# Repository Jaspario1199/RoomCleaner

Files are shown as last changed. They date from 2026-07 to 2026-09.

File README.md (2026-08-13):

# RoomCleaner 🧺🤖

An autonomous robot that scans your room, spots dirty laundry on the floor,
picks it up, and drops it in the hamper — using four winch motors in the
ceiling corners and a downward-facing gripper on cables.

> **▶ Interactive showcase:** [`showcase/index.html`](showcase/) — a live,
> self-contained portfolio page (browser simulation + engineering analysis +
> CAD). Open it in a browser or host it free on GitHub Pages.

> **Status:** Phase 0 complete + Phase 1 scaffolded. The kinematics, fan-aware
> motion planning, auto rest-pose, and the full scan→grab→deliver loop run today
> with **zero hardware**; a real open-vocabulary laundry detector runs on a
> webcam. You only need to fill in your room dimensions and ceiling-fan location.

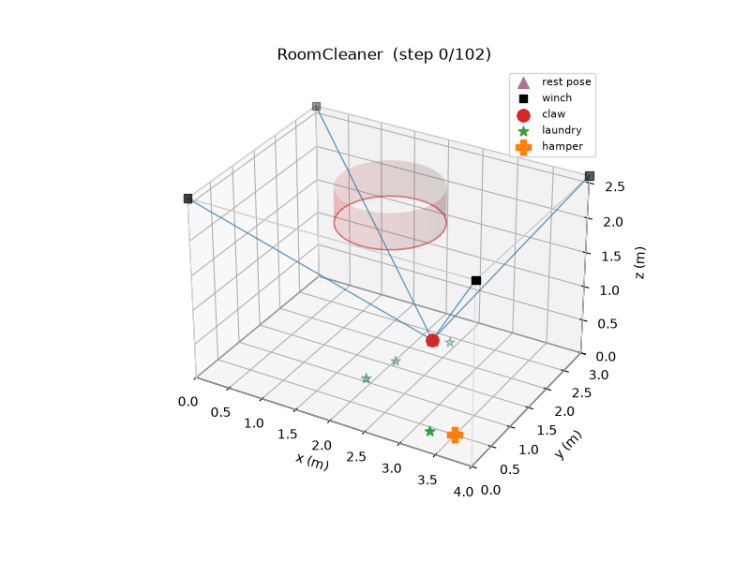
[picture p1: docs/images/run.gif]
A cleaning run in simulation


---

## The idea in one picture

The machine is a **Cable-Driven Parallel Robot (CDPR)** — the same mechanism
that flies the "SkyCam" over a football stadium. Four motorized winches sit in
the ceiling corners; each pays out or reels in a cable. Where the cables meet is
the end-effector (the "claw"). Control the four cable lengths and you control the
claw's position anywhere in the room.

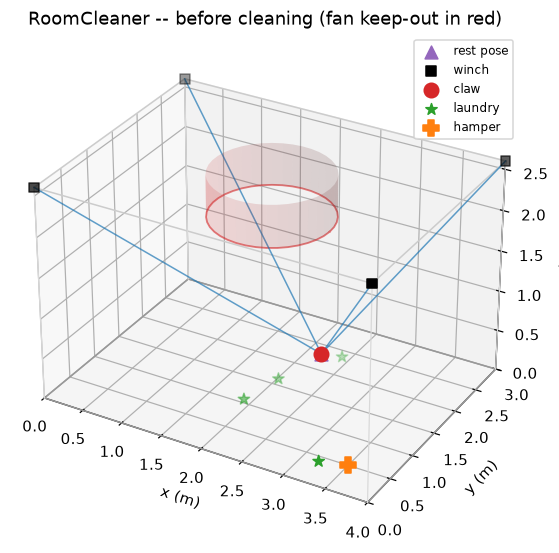
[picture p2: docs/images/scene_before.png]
The robot in its room


**Why a cable robot instead of arms or a rolling vacuum?**
- It reaches the *whole floor* from above — no bumping into furniture.
- The heavy motors stay bolted to the ceiling; only a light claw moves.
- The math (below) is clean and the parts are cheap.

The trade-off is the reachable area shrinks near the walls (cables can't pull the
claw sideways into a corner). Here's the safe workspace at a low height — green is
reachable, pink is not:

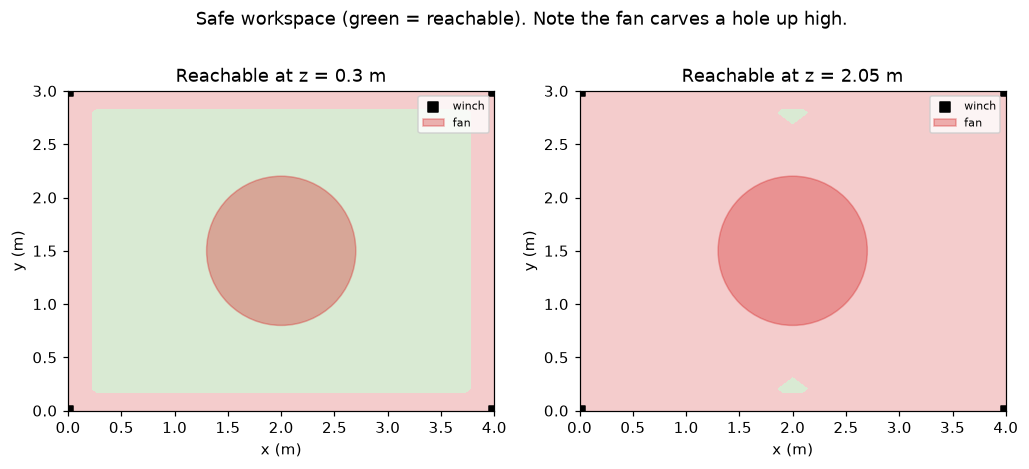
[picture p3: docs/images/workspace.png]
Reachable workspace


That pink border is a real design constraint: **laundry pushed right against a
wall is a hard case** we'll have to handle (e.g. a longer-reach end-effector, or
just accepting a small dead-zone).

### The ceiling fan is a hard no-go zone
If you have a ceiling fan, the robot's cables must **never** touch it. RoomCleaner
models the fan as a vertical keep-out cylinder and geometrically checks *every
cable* against it — a point is only reachable if all four cables clear the fan and
the claw stays out of it. The claw also **cruises below the fan** and **parks at
an auto-computed rest pose** out of the way between jobs. You just enter the fan's
center, blade radius, and how far it hangs down; the math does the rest. Good
news from the workspace map: laundry *under* the fan is still reachable, because
when the claw drops low the cables splay out to the corners and clear the blades.

---

## Quick start

```bash
pip install -r requirements.txt
python -m scripts.demo_sim       # 3D animation of a full cleaning run
python -m scripts.sim_tension_map  # heatmap: where the motors strain hardest
python -m scripts.sim_pickup_run   # per-pickup height / cable length / tension plots
python -m scripts.sim_payload_sweep         # max liftable weight, anywhere in the room
python -m scripts.sim_calibration_sensitivity # how precisely to measure your ceiling
python -m scripts.sim_workspace_volume      # 3D render of the reachable volume
python -m pytest                 # run the kinematics/geometry/vision tests

# Phase 1 — real laundry detection on a webcam (heavier deps):
pip install -r requirements-vision.txt
python -m scripts.detect_webcam                    # detect + print floor coordinates
python -m scripts.detect_and_plan --image floor.jpg  # full pipeline: detect -> localize -> PLAN
```

### The console (operator dashboard + live perception, one app)

A local single-page web app for watching and driving the robot from a browser:

```bash
pip install -r requirements-app.txt        # just Flask; core deps cover the rest
python -m roomcleaner.app --sim            # http://127.0.0.1:8000
# or:  python quickstart.py --app          # installs + launches in one step
python -m roomcleaner.app --live --camera 1  # real camera feed + detections
python -m roomcleaner.app --live --demo      # no camera: simulated laundry,
                                             # real detection→plan pipeline
```

It shows a live feed (MJPEG) with detection boxes and a sensitivity slider,
a detected-items panel with floor coordinates, status cards (phase, claw
position, items picked, claw link/battery), per-cable tension bars checked
against the 0.5–40 N motor band, a **Robot & plan** panel (nearest-first
pickup order + per-target cable lengths A–D + max tension + reachability), a
**3-D room view** with a Live view / Animate plan toggle, a scrolling
operations log, and operator controls: Start / Pause / Resume / STOP, Home,
Park, Grip/Release, a 0.1 m jog pad (workspace-clamped, fan keep-out
enforced), and a settings drawer for room/fan/hamper geometry. `--live` runs
the real camera through the validated capture+inference threads and wires the
serial winches + WiFi gripper only if they are reachable (otherwise
camera-only, motion disabled — bench-validate motion first). Details:
[`docs/APP.md`](docs/APP.md). The software STOP is not a safety device — the
physical kill switch remains the power strip.

`detect_and_plan` is the end-to-end brain: it takes a top-down photo (or
`--webcam 0`), detects the laundry, maps each item to a floor coordinate, runs
the real pickup planner, and saves an annotated image + a 3D scene. Test it on a
phone photo today — no camera or robot required.

The sim demo scatters fake laundry, then runs the real control loop to clear the
floor and animates the result. **Before anything else, open
`roomcleaner/config.py` and fill in the two "EDIT ME" blocks** — your room
dimensions and your ceiling-fan location/size.

---

## How it works (the four subsystems)

### 1. Kinematics — `roomcleaner/kinematics.py`
The core math, and it's simpler than it looks:

- **Inverse kinematics** ("put the claw *here* → how long is each cable?") is just
  the straight-line distance from each ceiling anchor to the target point.
- **Forward kinematics** ("cables are *these* lengths → where's the claw?") is a
  least-squares fit, because real cable measurements are never perfectly
  consistent.
- **Statics** ("can four *pull-only* cables actually hold the claw here without
  exceeding the motor's force limit?") defines the usable workspace. Cables can
  pull but never push, so this is the constraint that carves out those pink edges.

### 2. Perception — `roomcleaner/perception/`
Finds laundry and locates it on the floor. A `SimulatedDetector` invents laundry
for the sim, and `YoloWorldDetector` does the real thing on a webcam using an
**open-vocabulary** model (detects "sock", "towel", … from *words*, no training).
Both share the **exact same interface**, so the control loop never changes.
`localization.py` maps a camera pixel to a floor `(x, y)` — zero-calibration for a
straight-down ceiling camera, or a precise 4-point homography for a tilted one.
See **[docs/VISION.md](docs/VISION.md)**.

### 3. Motion planning — `roomcleaner/control/trajectory.py`
Turns "go to point X" into a smooth, ease-in/ease-out path. The `safe_transit`
helper always travels *up → across → down* so the claw never drags across the
floor or clips furniture.

### 4. Orchestration — `roomcleaner/control/state_machine.py`
The brain: an explicit state machine
(`SCAN → SELECT → APPROACH → GRAB → DELIVER → DONE`) that clears the floor one
item at a time, nearest first. Keeping it an explicit state machine (not tangled
`if`s) makes safety easy to reason about and new states easy to add.

---

## Repository layout

```
roomcleaner/
  config.py               # ROOM + FAN dimensions, motor limits, margins — the ONLY file you edit
  kinematics.py           # inverse/forward kinematics + statics/workspace + rest-pose finder
  geometry.py             # fan keep-out: exact cable-vs-cylinder intersection tests
  simulator.py            # 3D visualiser (renders to PNG/GIF, no display needed)
  perception/
    detector.py           # Detector interface + SimulatedDetector
    vision_detector.py    # real open-vocabulary laundry detector (YOLO-World)
    localization.py       # pixel → floor (x,y): overhead-linear + homography mappers
    camera.py             # webcam capture wrapper (OpenCV)
  control/
    trajectory.py         # smooth path generation
    state_machine.py      # the scan→grab→deliver brain (emits move/grip/release actions)
  hardware/
    driver.py             # positions → winch steps + serial protocol (Serial/Mock)
    gripper.py            # gripper backends: WiFiGripper (wireless claw) / Serial / Mock
    executor.py           # stream a plan to the motors + gripper
    hw_config.py          # steps/rev, microstepping, drum dia, serial port, effector IP
firmware/
  roomcleaner_firmware/   # Arduino sketch: 4 winch steppers + homing (wired)
  effector_esp32/         # ESP32 sketch: wireless gripper servo over WiFi
scripts/
  demo_sim.py             # end-to-end simulation demo
  detect_webcam.py        # live laundry detection from a webcam
  detect_and_plan.py      # full pipeline: image/webcam → detect → localize → plan
  hardware_dryrun.py      # print the serial command stream (no Arduino needed)
tests/
  test_kinematics.py      # the math we must trust
  test_geometry.py        # fan keep-out safety tests
  test_localization.py    # pixel → floor mapping tests
docs/
  ROADMAP.md              # phase-by-phase build plan
  HARDWARE.md             # BOM (cheap Amazon parts) + gripper recommendation
  VISION.md               # perception & camera calibration guide
  ARCHITECTURE.md         # how the pieces fit + the design decisions
  RESEARCH.md             # sources behind the hardware/gripper choices
```

---

## Where this is going

See **[docs/ROADMAP.md](docs/ROADMAP.md)** for the full plan. The short version:

| Phase | What | Cost |
|---|---|---|
| **0** ✅ | Kinematics + simulator + control loop + fan safety + rest pose | Free (software) |
| **1** 🚧 | Real laundry detection & floor localization (runs on a webcam) | Free–cheap (a webcam) |
| **2** | Motion planning polish, full-path safety, sim tuning | Free |
| **3** | Hardware bring-up: motors, drivers, camera, e-stop | 💰 the build (~$250–515, see BOM) |
| **4** | The grasp — actually picking cloth off the floor | 💰 the experiment |

The two genuinely hard, risky parts are called out honestly in the docs:
**grasping deformable cloth** (Phase 4) and **safety** (a motor that can move a
payload across your ceiling can hurt someone). We de-risk everything cheap in
software first.

---

## The gripper — a tentacle hand (mechanical, no vacuum)

Grabbing crumpled cloth off a hard floor is the classic failure point. The chosen
design is a **ring of tendon-driven curling "tentacle" fingers** that descend and
curl **inward and under**, raking and wrapping the laundry toward the center — one
servo closes them all. For real, crumpled laundry this beats a rigid claw because
it gathers rather than needing something to pinch. It's fully modeled and
print-ready in **[`cad/`](cad/)** (`tentacle_finger` × 5 + `tentacle_hub` +
`effector_frame`). Full reasoning and the needle-gripper fallback are in
**[docs/HARDWARE.md](docs/HARDWARE.md)**.

## 3D-printed parts (CAD)

Everything mechanical that can be printed is provided as **parametric CadQuery
scripts** exporting genuine **STEP** + **STL** files: winch spools, motor mounts,
corner guides, the end-effector frame, and the whole tentacle gripper. Edit your
dimensions in `cad/params.py` and run `python -m cad.export_all` to regenerate.
See **[cad/README.md](cad/README.md)** for print settings and assembly. (The
load-bearing ceiling anchors stay **metal** — never printed.)

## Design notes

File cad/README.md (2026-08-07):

# RoomCleaner — 3D-Printed Parts (CAD)

Every printable part, as **parametric CadQuery scripts** that export genuine
**STEP** files (open in Fusion 360 / SolidWorks / FreeCAD / Onshape) and **STL**
files (ready to slice). The generated files are committed, so you can print
without installing anything.

```
cad/
  params.py         # ← edit YOUR dimensions here (shaft dia, line dia, servo…)
  parts/*.py        # one parametric script per part
  export_all.py     # regenerate everything + an assembled gripper preview
  lib.py            # STEP/STL export + PNG preview helper
  step/  stl/  previews/   # generated output (committed)
```

## Parts list

| Part | What it is | Print | Material |
|---|---|---|---|
| `winch_spool` | Drum the Dyneema winds onto; mounts on the motor shaft | ×4 | PLA/PETG |
| `corner_mount` | **Rigid corner anchor plate**: NEMA 17 bracket + pulley ears on one base, screwed to a joist/stud with 3× #10×3" wood screws (D13) | ×4 | PETG |
| `motor_mount` | (superseded by `corner_mount` for the corner install; kept for bench use) | — | PETG |
| `corner_guide` | (superseded by `corner_mount` for the corner install; kept for bench use) | — | PETG |
| `effector_frame` | Hangs on the 4 cables; holds servo, camera, + strap slots for the ESP32 & LiPo (wireless claw) | ×1 | PETG |
| `tentacle_hub` | Disc carrying the ring of fingers; routes tendons | ×1 | PETG |
| `tentacle_finger` | Tendon-driven curling "tentacle" finger | ×5 | **TPU 95A** |
| `camera_mount` | Pi Camera bracket for the effector (close-up cam, Phase 4) | ×1 | PLA/PETG |
| `camera_mount_overhead` | Ceiling bracket for the innomaker 32×32 overhead cam | ×1 | PLA/PETG |
| `standoff` | 40 mm column joining frame to hub (insert both ends) | ×4 | PETG |
| `tendon_drum` | Flanged spool on the servo horn; winds all 5 tendons | ×1 | PETG |
| `electronics_cover` | Screw-down lid over servo + ESP32 + LiPo (switch/USB cutouts) | ×1 | PETG/PLA |

## Regenerate after changing dimensions

Edit `cad/params.py` (especially `MOTOR_SHAFT_DIA`, `DYNEEMA_DIA`) then:

```bash
pip install -r requirements-cad.txt
python -m cad.export_all
```

## Print settings

- **Structural parts** (spool, motor mount, corner guide, frame, hub, standoffs, drum, cover): **PETG**,
  0.2 mm layers, **4 walls**, **40–50% infill**. These carry real load.
- **Tentacle fingers**: **TPU 95A**, 0.2 mm, 3 walls, 15–20% infill. Lay each
  finger on its **flat dorsal (back) face** so the V-notches open upward — no
  supports. Slow down to ~20–30 mm/s for clean TPU.
- Most parts print support-free in the orientation described in each script's
  docstring.
- Tune `CLEARANCE` in `params.py` if press-fits are too tight/loose on your printer.

## Corner-mount assembly note (fleet alignment)

When sliding each `winch_spool` onto its motor shaft, set the gap between the
spool's near flange and the bracket wall to **at most 2 mm** before tightening
the grub screw (a folded piece of paper card ≈1 mm makes a good feeler). The
CAD models the flange flush with the wall; every millimeter of real gap shifts
the drum off the pulley's groove plane by the same amount, and 2 mm is the
budgeted ceiling (verified: ≤2 mm keeps worst-case fleet angle ≈9°, within
tolerance). Don't run the flange rubbing the wall — aim for ~1 mm.

## Assembling the claw (D2–D8 stack-up — matches `claw_assembly.step`)

**Inserts first.** Press M3 heat-set inserts into: both ends of each `standoff`
(8 total) and the 4 cover-tab holes in the frame's top face. (No inserts in TPU.)

1. **Zero the servo.** Power the ESP32 and hit `GET /setup` — the servo parks at
   RELEASE (20°). Screw the round horn into the `tendon_drum`'s top pocket
   (4× Ø2.4 self-taps), then press horn+drum onto the spline in this position
   and lock with the M3 horn screw through the drum's central Ø6.5 hole.
2. **Mount the servo INVERTED**: body above the plate, spline down through the
   frame pocket; ears screw to the plate top (M3 self-tap, 2.8 mm holes).
   The drum now hangs under the plate, tie-off flange facing down.
3. **Standoffs to frame**: M3×8 down through the frame's clearance holes into
   each standoff's TOP insert (bolt circle Ø54, angles 36/108/252/324°).
4. **Fingers into hub** (before the hub goes up): insert each finger from
   BELOW through its slot, **notched (ventral) side facing the hub center**,
   until the shoulder seats on the hub underside; retain with an axial
   **M3×12 + washer** from the hub top into the finger's base tap.
5. **Hub to standoffs**: **M3×16 + washer** up through the hub (head on the
   hub underside) into each standoff's BOTTOM insert.
6. **Tendons** (Dyneema, same 50 lb line): tie off at each fingertip's cross
   hole, run down the finger channel, in through the hub guide hole, up the
   central bore, and tie to the drum's bottom-flange holes — reaching up
   through the hub bore. With the servo still at RELEASE and fingers straight,
   pull each tendon just-taut before knotting; re-tension individually later
   through the same bore access.
7. **Electronics**: set the buck to **6.0 V before connecting the servo**;
   strap the ESP32 (+y band) and LiPo (−y band) with zip ties; wire
   LiPo → switch → buck → servo + ESP32 VIN, common ground.
8. **Cover**: seat over everything, screws into the 4 frame tab inserts;
   switch and USB accessible through the cutouts; the corner notches leave
   the cable bosses exposed.
9. **Cables**: Palomar knot through each corner boss (Ø3.2). The Pi Camera
   (`camera_mount`, Phase 4) clips to the frame edge later.

**First-print validation set (do this before printing everything):** frame,
4× standoff, hub, drum, ONE finger — verify slot fit, shoulder seating, and
~27 mm of tendon travel over the 120° throw, then print the rest.

## Heat-set inserts (brass threaded inserts)

`params.py` has `USE_HEATSET_INSERTS` (default **True**). It controls only the
holes where a screw threads **into printed plastic**:

- **Insert holes:** BOTH ends of each `standoff` (8 inserts — these carry the
  whole gripper) and the 4 cover-tab holes in the frame top. Melt each in with
  a soldering iron + insert tip.
- **Left as clearance / screw-through:** the frame's and hub's Ø-holes on the
  bolt circle (screws pass through into the standoff inserts — the hub's 4 mm
  holes are deliberately loose; the washer seats the head), the servo ear taps,
  and everything that threads into motor/servo metal.
- **TPU parts stay self-tap / use a screw + nut:** heat-set inserts do **not** hold
  in flexible TPU, so the `tentacle_finger` base is not insert-drilled.

Set `USE_HEATSET_INSERTS = False` and re-run `python -m cad.export_all` if you'd
rather self-tap screws straight into the plastic (holes shrink to ~2.8 mm).

## ⚠️ Safety: do NOT print these

The **load-bearing ceiling anchors** (the eye screws / lag bolts into your
joists) must be **metal**, driven into solid wood — never a printed part. The
whole robot hangs from them. `motor_mount` and `corner_guide` bolt *to* those
metal anchors; the anchors themselves stay steel. Same for the emergency-stop
hardware.

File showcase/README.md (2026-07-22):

# RoomCleaner — Interactive Showcase

`index.html` is a **self-contained** portfolio page (no build step, no external
assets — the CAD render and all charts are inlined). Great for recruiters.

## View it
Just open `showcase/index.html` in any browser.

## Host it free on GitHub Pages (permanent portfolio link)
1. Push this repo to GitHub.
2. Repo **Settings → Pages → Source: Deploy from a branch**, pick your branch and
   `/root` (or move this file to `/docs`).
3. Your page goes live at `https://<you>.github.io/<repo>/showcase/`.

## What's on it
- A **live browser simulation** of the control loop (scan → grab → deliver) with
  telemetry — the same kinematics the real robot uses, in JS.
- Native, theme-aware charts: the **cable-tension cost map** and the
  **max-payload** analysis, rendered from the physics.
- The tentacle-gripper CAD render, the tech stack, and the headline specs.
- Light/dark theming, responsive, keyboard-friendly.

It's regenerated from the project's real numbers — if the design changes, update
the stats in the HTML to match.

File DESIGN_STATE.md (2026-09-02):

# Design State

## Repository adaptation map (per CLAUDE.md structure)
- parameters.py → `cad/params.py` (re-exports contracts from `cad/interfaces.py`)
- interfaces.py → `cad/interfaces.py` · materials.py → `cad/materials.py`
- parts/ → `cad/parts/` · exports/ → `cad/step/`, `cad/stl/` · renders/ → `cad/previews/`
- tests/ → `tests/` (pytest) · calculations/ → `calculations/` · verification/ → `verification/`

## Current gate
Gate 4 (bounded implementation) — Gates 1–3 recorded this session:
REQUIREMENTS.md, DECISIONS.md (D1–D10), calculations/claw_integration.md (C1–C6).

## Architecture (claw integration pass, two-pass reviewed)
Inverted MG996R on plate → flanged tendon drum (bottom tie-offs, reachable
through hub bore) → 40 mm standoffs on unified Ø54 bolt circle at
[36°,108°,252°,324°] → hub with THROUGH finger slots → shouldered TPU fingers.
Electronics strapped on plate top under a screwed cover (switch/USB cutouts,
corner cable notches).

## Known risks / open items
- Latent bug FIXED in contracts, pending in geometry: frame used r=27 @45°+90k,
  hub used r≈23.6 — both must be regenerated to the shared contract.
- MP1584 3 A vs servo stall marginal (D10) — electronics BOM watch item.
- C1 travel assumption (full notch closure) to be trimmed at bench test.
- Jeans-size wrap volume may want FINGER_LEN 70→90 (parameter change only).

## Gate 4 complete (this session)
1. ✅ calculation-checker: C1–C6 reviewed — caught servo-throw/firmware
   inconsistency (100° vs 120° — would have undersized the drum), stale R18,
   mass-rollup arithmetic (406 g). Contracts corrected; report in verification/.
2. ✅ cad-implementer A: standoff (10×10×40), tendon_drum (33×33×12.4),
   electronics_cover (98.8×98.8×44.4) — contract-sourced, lead-reviewed.
3. ✅ cad-implementer B: hub through-slots + unified bolt circle, finger
   shoulder (bbox 20×17×70) + NOTCH_GAP import, frame ear-taps/cover inserts,
   EFFECTOR_REACH=0.13 + GRAB_Z derived, GRIP_ANGLE 120→140, firmware /setup.
   Known: tests/test_hardware.py "G 120" assertion stale → verifier owns fix.

4. ✅ geometry-verifier: ALL PASS — 6 parts exact bboxes, bolt-circle identity,
   through-slots, drum capacity 28.27 mm, cover/frame alignment, STEP round-trips
   0.0000 diff; mass rollup 419.2 g ≤ 450 (A3). 42 new geometry tests.
5. ⚠→✅ LEAD-CAUGHT SPEC ERROR before integration: finger shoulder was specced
   at the mounting end (z 0–2), which would have blocked slot insertion
   entirely. Contract corrected (FINGER_SHOULDER_Z0 = HUB_THK, both now in
   interfaces.py; hub imports HUB_THK), finger fixed, stale test updated.
   71/71 pytest green.

6. ✅ integration-agent: real stack-up assembled; pairwise interference all
   0.000 mm³ (after catching a 6.5 mm finger placement offset, D11); slot
   engagement 100 % ×5; drum↔standoff 5.5 mm; assembly STEP round-trip exact.
   Reach measured 118 mm → contract corrected (D12). 71/71 pytest.

## Gate 7 audit notes (lead, this session)
- (low) DRUM_TOP_Z = −6 is assembly-local; verify real MG996R spline+horn
  stack-out below the plate at bench; adjust drum z or GRIP tuning if needed.
- (med) Tendon bend at hub guide-hole exits: chamfers specified, friction not
  modeled — bench item with Dyneema.
- (low) Cover↔servo wire routing clearance unmodeled (42 mm inner height OK).
- Physical validation plan: print frame + standoffs + hub + drum + ONE finger
  first; verify slot fit, shoulder seating, tendon travel ≈27 mm, THEN print
  the remaining fingers and the cover.

## Tier 2 closure (winch-side verification + docs)
- geometry-verifier swept the 5 pre-discipline parts: motor_mount,
  camera_mount, camera_mount_overhead PASS. Two REAL defects found:
  winch_spool D-flat was a geometric no-op (cut box ended at the bore
  surface); corner_guide ear walls 0.15 mm (unprintable).
- cad-implementer repaired both (flat via bore-cutter ∩ half-space, wall
  2.100 mm exact; EAR_PLATE_T=7.0, walls 1.65 mm) and correctly ESCALATED a
  defective verifier test (hardcoded nominal arithmetic, never probed the
  solid). Lead authorized and rewrote the test to probe built geometry.
- Fastener-length contracts trued (hub-side standoff M3x16; finger retainer
  M3x12); cad/README assembly procedure + insert map rewritten to the real
  D2-D8 stack-up, incl. single-finger validation print.

## corner_mount cycle (D13, user-initiated: rigid anchors replace eye hooks)
Full Gate 4→5 loop on the new part, 3 defects caught by process:
1. Lead spec was self-contradictory on fleet alignment; implementer correctly
   flagged instead of silently resolving, but chose a layout where the line
   pays off perpendicular to the pulley groove. Lead ruling: spool axis ∥
   pulley axle, drum mid-plane coplanar with groove plane. Repaired.
2. geometry-verifier found gussets intersecting the NEMA 17 motor-body
   envelope (70.42 mm³ — motor couldn't seat). Repaired: wall 56 mm, gussets
   driven off real body half-width + 2 mm; BASE 138×65, mass 88.76 g ≤ 90.
3. Verifier test-audit: several nominal-only assertions upgraded to
   solid probes; boolean interference regression tests added (proven to fail
   on the pre-repair geometry). Residual low-risk gap: fleet-angle test is
   still arithmetic-only.
Re-verification: all measurements reproduced independently, both
interference volumes 0.000 mm³, STEP round-trip exact. FACE_TO_SPOOL=0
assessment: spool rub-gap ≤2 mm is the assembly ceiling (documented in
cad/README.md); at 2 mm, worst-case fleet ≈9° < 15° threshold.
Watch item: back-margin behind wall is 10.5 mm vs GUSSET_RUN=10 (0.5 mm
slack) — re-check if gussets are ever enlarged.

## Pending physical measurements (user's calipers unavailable — blocking two prints)
- MG996R round plastic disc horn: outer diameter, thickness, opposite
  screw-hole spacing → sets HORN_POCKET_DIA (+depth) → tendon_drum print.
- Motor shaft across-flat: D-flat CONFIRMED visually on the 17HS4401s;
  MOTOR_SHAFT_FLAT=0.5 assumed (standard). Caliper check ≈4.5 mm across the
  flat when available; winch_spool cleared for a single fit-test print
  meanwhile.

## Current gate
Gate 6 complete for the claw; corner_mount verified (Gate 5) →
release-candidate items remaining: SOLIDWORKS review (claw_assembly.step),
physical validation plan, winch-corner assembly preview incl. corner_mount.

## Last verified state
130/130 pytest; 12 parts exported and verified; claw_assembly.step
round-trips exactly; corner_mount re-verified at commit a9c1a51.

## Local bring-up findings (software + camera session, 2026-08-12)
Separate from the CAD workflow — no `cad/` files changed. The software + live-
camera milestone was brought up on-machine and a browser console app was built
(see `BRINGUP_LOG.md` and `docs/APP.md`; live camera = innomaker index 1).

Two CAD **casing gaps** surfaced while auditing the BOM against the exported
parts — components in `docs/BOM_ORDER.md` that are mounted but have no printed
enclosure/bracket (candidates for a Gate-4 pass if the user wants them):
1. **Base-station controller enclosure** — Arduino Uno + CNC shield + 4×
   A4988/DRV8825 + fuse/wiring. `electronics_cover` covers ONLY the effector's
   servo/ESP32/LiPo; there is no case for the ground controller.
2. **Limit-switch (KW12-3) mount** — `corner_mount` unifies the NEMA-17 bracket
   + pulley redirect only (no switch pocket); no dedicated switch bracket
   exists. Homing (`docs/FIRMWARE.md` "S switch test") needs these mounted.

Everything else being mounted (4× motors → corner_mount, spools, overhead cam →
camera_mount_overhead, servo, effector electronics, the whole claw) already has
a printed part with a committed STEP.
## Operator dashboard (software interface milestone)
`python -m roomcleaner.app --sim|--live` — Flask + single-page dark UI:
MJPEG live feed (sim renders a top-down synthetic camera; live wires the
real Webcam+YOLO), status cards, per-cable tension bars vs [0.5,40] N,
plan-vs-executed operations log, mission controls + guarded jog pad
(workspace clamp + fan keep-out server-side), room/fan/hamper settings.
Lead-verified headless (Playwright): mission runs real-time, jog moves
pose when idle and is disabled while running, settings drawer OK, no JS
errors. 141/141 tests. Live mode needs bench validation (see docs/APP.md).

## Console convergence (next bounded software task — run on the CAMERA machine)
Two consoles were built the same day on opposite sides (local: live
perception console `scripts/live_app.py` : 8000, validated on the real
innomaker; cloud: operations console `roomcleaner/app` : 8010, validated in
sim). Target: ONE app — the operations console's session/command
architecture absorbs the perception console's proven capture/inference
threading (as LiveSession's feed) and its plan/3-D panels. Must be executed
and validated where the camera is; docs/APP.md documents both until then.

## CAD gap closure (both local-session findings resolved)
1. corner_mount rev B: KW12-3 homing-switch boss (bead-trips-lever), M2
   slots + zip-tie fallback, ±5 mm adjustability; verified, committed.
   Bench items: confirm switch dims (~20 mm body / 9.5 mm hole pitch) on
   the purchased units; set lever reach in the slots with the line strung.
2. base_station_case (tray + lid, 135.15 g): full loop took 2 verification
   passes + 2 repairs, 5 real defects caught pre-print — mid-air
   countersinks (workplane-centroid trap), USB port rotated 90°, lid posts
   inside the Uno footprint, one Uno hole coordinate 1.27 mm off vs a
   KiCad footprint, and zip-tie holes merging across the motor↔endstop
   port boundary (fixed by Z-flanking; also cured a 0.75 mm sliver on the
   input wall). Final verdict PASS; 185/185 tests. Assumption on record:
   CNC-shield connector heights are estimates absorbed by oversized
   strain-relieved ports.
Print queue when the printer returns: 4× corner_mount (rev B), 1× spool
fit-test, claw stack (frame/standoffs/hub), base_station_case tray+lid,
camera_mount_overhead. Still gated: tendon drum (horn measurement), fingers
(TPU).

## Console convergence — DONE (8/13)
One app now: `python -m roomcleaner.app` (--sim | --live --camera N |
--live --demo), port 8000. The operations console's session architecture
absorbed the camera-validated capture/inference pipeline (now
roomcleaner/app/perception.py), detected-items panel + conf slider, plan
panel (per-target A–D cable lengths/tension/reachability), 3-D room view +
animate-plan GIF. roomcleaner/webapp deleted; scripts/live_app.py is a
forwarder. Lead-verified headless in --sim (mission playback) and
--live --demo (real detect→plan pipeline, motion correctly 409-gated,
camera-only banner). 192/192 tests. Outstanding: the physical-camera smoke
test on Jasper's machine (local agent's first task per UPDATE_8-13.md),
plus the pre-existing live-motion bench items (docs/APP.md).

## Camera case — DONE (8/28)
New part camera_case_overhead (shell + bezel) fully encloses the innomaker
board on the ceiling: 56x56 plate + 24.6 mm skirt, board on 10 mm M2
standoffs (28 mm pitch imported from camera_mount_overhead), O18 lens
opening in a screw-on bezel, cable exit through-plate or side notch at USB
level. 45.0 g PETG (60 g budget). Independent verification PASS (52/52;
verification/camera_case_overhead_report.md). It supersedes the open
camera_mount_overhead bracket in the print queue (bracket file retained).
VERIFY before printing: 28 mm board hole pitch; lens-barrel OD (O18 opening
assumes M12). Watch items: skirt wall measures exactly the 2.4 mm floor;
side notch fits a flexible cable, not a rigid strain-relief boot.
Corner pulley ruling (8/28): BUY complete 3 mm-bore U-groove bearing
pulleys (OD 18-22, width <10 mm, ~10-pack) + M3x25 bolts/nylocks/washers;
printed sheave is fallback only. Corner_mount junction stresses checked:
ears 5.5 MPa worst-case (SF ~5 vs PETG layer adhesion), wall <0.5 MPa.

## Bench bring-up — Phases 1–5 DONE (8/28, live session)
Phase 2: 14 caps seated (12 microstep + 2 A-axis D12/D13). Phase 3: ALITOVE
plug cut, meter-identified + lead, 7.5 A inline fuse, shield terminal reads
**18 V** (brick label still to be read; within 12–36 V shield / 35 V A4988
spec — never feed the Uno barrel jack from it). No VMOT LED on this clone;
the meter reading is the checkpoint. Splice is twist + duct tape: REDO with
solder/heat-shrink or a lever nut in Phase 6. Phase 1: firmware flashed,
READY / POS / SW verified. Phase 4: drivers confirmed R100, all four Vref
set 0.75–0.85 V. Phase 5: one SIMAX motor spun 1 rev out/back on X, Y, Z
and A — 4th-axis mapping proven. Next: Phase 6 limit switches (soldering).

## corner_mount rev D — homing switch below the pulley, VERIFIED (8/28)
D14 implemented: mid-span switch boss removed; KW12-3 now sits on a
horizontal pad atop a drop arm beside the vertical line (roller at
DROP_X = EAR_CX + CORNER_PULLEY_OD_NOM/2, Y=1.0, Z=56.5 local); a
descending bead presses the roller toward the pad (-Z = reel-in). Rev C
(switch on the arm's vertical face) FAILED independent verification --
roller 5 mm off in X, 10.5 mm in Y (verification/corner_mount_revC_report.md);
rev D PASSES (verification/corner_mount_revD_report.md), plus D.1 fixes:
zip groove moved to Z 34.5-38.5 clear of the M2 pilots, r=3 corridor
notch at the pad front (0 mm^3 intrusion). Mass 96.29 g / 105 g budget.
100 corner-mount tests green. STL current -> print the 4-off set from this.
Caliper-verify on a KW12-3 in hand: roller overhang past body end
(assumed 1.5 mm), roller rest height above mounting face (12 mm),
hinged end (assumed far end). Trigger height is set by bead placement
(~4 mm below the roller contact). Bead nominal O5 (local assumption,
KW_HOMING_BEAD_DIA_NOM).

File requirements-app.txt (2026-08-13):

# Web console extras (the unified browser UI; the core package and CLI work
# without it): python -m roomcleaner.app --sim | --live | --live --demo
# Install alongside the vision stack for live camera mode:
#   pip install -r requirements-vision.txt -r requirements-app.txt
flask>=3.0

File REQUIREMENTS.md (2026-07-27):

# RoomCleaner — Requirements (mechanical scope: the claw / end-effector)

Judged success: the claw, hanging from four Dyneema cables, descends onto laundry,
closes five tendon-driven fingers with one servo, holds the item through transit,
and releases it — repeatably, with every part printable or on the approved BOM.

## Functional
- R1. Grip and hold items 0.05–0.9 kg (sock → jeans) during transit at ≤2 m/s² vertical acceleration.
- R2. Release reliably on command (servo return; gravity + finger springback eject the item).
- R3. All five fingers actuate from ONE MG996R-class servo (tendon drum).
- R4. Wireless effector: ESP32 + 2S LiPo + 6 V buck + power switch ride on the claw; only the 4 cables touch it.
- R5. Tendon pre-tension must be individually adjustable after full assembly.
- R6. Servo horn must be attachable at a known zero (RELEASE) angle via a documented procedure/firmware endpoint.

## Physical / envelope
- R7. Total claw mass ≤ 0.45 kg (the value the workspace/tension analysis assumed).
- R8. Vertical reach (cable plane → fingertips) ≈ 118 mm (integration-measured); recorded as EFFECTOR_REACH and consumed by the motion planner.
- R9. Fits within a 100 mm square footprint at the plate (cable clearance at the corners).

## Interfaces (authoritative details in cad/interfaces.py)
- R10. Servo: MG996R inverted (body above plate, spline down), ear-screwed to the plate.
- R11. Cables: 4× tie-offs at plate corner bosses (Ø3.2 holes), knot spec Palomar.
- R12. Frame↔hub: 4 printed standoffs on a shared bolt circle; heat-set M3 inserts + M3×8.
- R13. Fingers: base into hub through-slots from below, shoulder bears on hub underside (floor loads), axial M3+washer from above (gravity loads).
- R14. Electronics: strap-mounted on plate top; cover with switch + USB cutouts; cover must not intrude on cable corner cones.

## Manufacturing
- R15. FDM printable without supports in the documented orientations; PETG structural, TPU 95A fingers.
- R16. Threads in plastic use heat-set M3 inserts wherever fastened more than once.

## Loads
- R17. Worst case at the plate: 40 N per cable (motor limit). Claw structure margin ≥3 on that.
- R18. Servo torque budget: total tendon load ≤ 25 N at the drum; required torque ≤ 3.5 kg·cm (3.44 at DRUM_CORE_R=13.5) vs ~10 kg·cm available.

## Acceptance
- A1. Every part passes independent geometry verification (dims, interfaces, STEP round-trip).
- A2. Assembly integrates with zero static interference and documented clearances.
- A3. Mass rollup ≤ 450 g from measured part volumes × material density + purchased masses.
- A4. pytest suite stays green; EFFECTOR_REACH consumed by planner without breaking sims.

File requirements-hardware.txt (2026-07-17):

# Phase 3 hardware bridge -- only needed to talk to the real Arduino.
# The dry-run (scripts/hardware_dryrun.py) and all tests work without this.
pyserial>=3.5    # USB serial link to the Arduino firmware

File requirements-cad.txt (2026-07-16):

# CAD toolchain -- only needed to REGENERATE the STEP/STL files.
# The generated files in cad/step and cad/stl are committed, so you can print
# without installing any of this.
cadquery>=2.4     # parametric CAD, exports STEP + STL (built on OpenCASCADE)
trimesh>=4.0      # loads STL for the preview renderer
# numpy + matplotlib (already in requirements.txt) render the preview PNGs.

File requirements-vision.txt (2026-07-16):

# Phase 1 vision extras (heavy -- install on the machine with the camera/GPU).
# The core package works without these; they're imported lazily only when you
# run the real detector or webcam capture.
ultralytics>=8.1     # YOLO-World open-vocabulary object detection
opencv-python>=4.8   # webcam capture + image ops

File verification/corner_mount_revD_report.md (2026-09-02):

# corner_mount REV D — independent verification report

Scope: `cad/parts/corner_mount.py` rev D, the KW12-3 homing-switch mount
re-orientation (rev C's vertical-face, along-the-lever mount → a horizontal,
+Z-facing top pad, roller end toward the drop line) that fixes the severe
FAIL recorded in `verification/corner_mount_revC_report.md` check 5. This
report covers Gate 5 (geometry-verifier role) only, superseding nothing in
the rev B/rev C reports except where rev D explicitly changed geometry.

Verifier: geometry-verifier (Sonnet), read-only against `cad/parts/
corner_mount.py`. Every number below was reproduced independently: built
`corner_mount.make()` directly and probed the actual BRep (OCCT
`BRepClass3d_SolidClassifier` point-in-solid tests, bisection, planar-face
extraction, and boolean intersection volumes). The KEY CHECK (check 6)
deliberately re-derives the roller's world coordinates from **measured**
mount geometry (the pad's own found face, the pilot holes' own measured
X-center) rather than importing `corner_mount.KW_ROLLER_X/Y/Z` directly, per
the assignment. A fresh, independently written test file — `tests/
test_corner_mount_revD_verification.py` (27 tests: 25 pass, 2 strict-xfail
recording real defects found during this review) — backs every number here.
The implementer's own suite (`tests/test_winch_geometry.py`, 73 tests, 39
`corner_mount`-scoped) was re-run in full as a secondary signal (Section
10).

## Summary

| # | Area | Verdict |
|---|---|---|
| 1 | Regression — rev-B/C features unchanged | PASS |
| 2 | Solid validity, mass, bbox | PASS |
| 3 | Pad face, M2 pilots, zip groove | PASS, with one **NEW FINDING** (below) |
| 4 | Printability plate-down (no overhang > declared step) | PASS |
| 5 | Clearances (pulley, NEMA17, csk, line corridor) | PASS below taper; **NEW FINDING** above taper (below) |
| 6 | **KEY CHECK — bead/roller mechanism, from measured geometry** | **PASS (all five sub-checks)** |
| 7 | Bead set-back logic (HOME_BACKOFF), verified against firmware | PASS |
| 8 | STEP round trip, STL, preview | PASS |
| 9 | Implementer's two flagged judgment calls | reviewed, see Section 9 |

**Overall: rev D's core fix — the reason this revision exists — is
verified correct.** The bead/roller mechanism, evaluated from independently
measured pad and pilot-hole geometry (not the module's own claimed
constants), genuinely lands the roller on the drop line across the accepted
18–22 mm pulley OD range, in both X and Y, with room to spare. That is a
real, substantive correction of the rev C defect.

Two smaller, real, independently reproducible defects were found during
this review that the assignment did not explicitly name but asked me to
check for by construction (front-pilot depth vs. the groove; printed-vs-
purchased intrusion above the taper). Neither touches the KEY CHECK. Both
are recorded as strict-xfail tests so the suite stays green while the
defects stay on the record:

1. **Both M2 pilot slots' outboard (+X) tuning-cap tip loses its enclosing
   wall for the deepest 1.5 mm of the nominal 5.0 mm blind depth** — the
   X1-side zip-tie groove breaches into it. The specific question the
   assignment asked ("is the front pilot's blind depth shallowed by any
   groove?") is answered **no** at the hole's own center axis (still 5.0 mm
   exactly) — but a related wall-integrity issue exists at the slot's
   tuned-outboard extreme, on both pilots, not just the front one.
2. **A small, quantified sliver of PRINTED material (not the roller)
   intrudes on the generic line/bead corridor above the taper** — 1.125
   mm³ (using the assignment's own Ø6/r=3 mm corridor) or 6.524 mm³ (using
   the implementer's own more conservative r=4 mm corridor), confined
   entirely to the pad's own Z band. The assignment's own rule is "only
   the purchased switch may" intrude there; here the pad's accepted
   ≤1.5 mm capping step also does, by a small amount.

Reproduce: `python3 -m pytest tests/test_corner_mount_revD_verification.py
-v` and `python3 -m pytest tests/test_winch_geometry.py -k corner_mount -v`.

---

## 1. Regression — rev-B/C features unchanged

| feature | measured | expected | verdict |
|---|---|---|---|
| plate footprint | 138.000 × 65.000 × 6.0 mm | 138 × 65 × `CORNER_MOUNT_PLATE_T` | PASS |
| 3 countersinks (x = −55, −5, 45, y=0) | void top (z=5.5) and bottom (z=0.5, through-hole) at all three | void/void | PASS |
| `SPOOL_DRUM_MID_Y` | 0.0 (exact, by construction) | 0 | PASS |
| wall/gussets | `WALL_CX=-40, WALL_THK=6, WALL_W=56, GUSSET_RUN=10, GUSSET_HEIGHT=18, GUSSET_THK=4` | unchanged from rev C | PASS (module constants identical; NEMA17 body-box boolean re-verified 0 mm³, §5) |
| pulley ears | `EAR_CX=55.0, EAR_H=28.5, EAR_SY=(±10)` | unchanged | PASS |
| ear mirror symmetry | 2000-point random probe on standalone `_pulley_ears()`, mirrored Y→−Y | 0 mismatches | PASS |
| mid-span region (X∈[−30,45]∖ear, Y∈{4..30}, Z∈{plate+0.5,+3,+7,+12}) | 0 solid hits (rev-B boss confirmed still absent; rev-D arm has not spread into it either) | empty | PASS |

`corner_mount.make()` bounding box is now **138.000 × 65.000 × 50.000 mm**
(X:[−69,69] Y:[−32.5,32.5] Z:[0,50]) — shorter in Z than rev C's 60.5 mm,
because the rev-D pad tops out at world Z=44.5 while the (unchanged) motor
wall now sets the part's overall height (`PLATE_T+WALL_H = 6+44 = 50`).
This is a legitimate side effect of the mechanism fix (rev C's arm was
taller than the wall; rev D's is not), not a regression.

## 2. Solid validity, mass, bbox

- `solids()` count = **1**, `isValid()` = **True**
- `Volume()` = **75818.664 mm³** (75.819 cm³)
- Mass @ PETG 1.27 g/cm³ = **96.290 g**, budget **105.0 g** → **8.710 g
  margin**.
- KW12 mount's own added mass (standalone `_kw12_mount_arm()` volume) =
  **7.527 g**, ceiling 10 g — PASS, with more margin than rev C's arm
  (8.433 g) since the rev-D post is a single member, not split legs, and
  shorter overall.
- `BoundingBox()`: **138.000 × 65.000 × 50.000 mm**.

All PASS.

## 3. Pad face, M2 pilots, zip-tie groove

**Pad face — found directly by planar-face extraction (not assumed):**
exactly one horizontal (+Z normal) planar face exists at world Z, matching
`PLATE_T + EAR_H + 10 = 44.500 mm`, with measured extent **X∈[59.800,
69.000] mm, Y∈[2.500, 24.000] mm** — matches the assignment's stated
expected range exactly, and `X1=69.000` sits exactly on the plate's own
`BASE_L/2` boundary (the pad is legitimately capped there, never past it).

**M2 pilots (both):**

| | measured | expected |
|---|---|---|
| narrow-axis diameter | 1.700 mm | Ø1.7 |
| X half-length | 2.850 mm (5.700 mm total) | ±2 mm tune + 1.7 mm dia = 5.7 mm |
| X center | DROP_X = 65.000 mm (both pilots) | centered on DROP_X |
| Y (front / back) | 7.750 / 17.250 mm | 2.5+5.25=7.75, 2.5+20−5.25=17.25 |
| blind depth (center axis) | 5.000 mm | ≥5.0 mm |

All PASS, exact match.

**Zip-tie groove:** confirmed void (recessed) on the X0, X1, and Y_hi
faces within the groove's Z band (37.0–41.0 mm world); confirmed **solid**
(un-recessed, as documented) on the front (−Y) face at the same Z. Matches
the implementer's stated design.

**Front pilot's own blind depth vs. the groove (the assignment's literal
ask):** measured solid at `KW_PAD_Z − KW12_PILOT_DEPTH − 0.3` along the
pilot's own center axis (X=DROP_X) → **confirmed NOT shallowed**, still
exactly 5.0 mm. **PASS**, as asked.

### NEW FINDING: pilot slot outboard-tip wall breach (both pilots)

Investigating the same groove/pilot interaction more thoroughly (scanning
across the full pilot slot footprint, not just its center axis) found that
the groove's Z band (37.0–41.0 mm world) overlaps the pilot hole's own Z
occupancy (39.5–44.5 mm world) by 1.5 mm, and the X1-side groove strip
(which — being one leg of a "picture-frame" ring cut — spans the **entire**
Y width of the arm, not just a local patch) reaches inward to X=67.5, while
the pilot slot's own outboard cap extends out to X=67.85 (0.35 mm of
X-overlap). Net effect, measured directly:

| Z below pad top | wall present between slot cap (x=67.85) and pad edge (x=69.0)? |
|---|---|
| 0.50 mm | solid (yes) |
| 1.00–3.00 mm | solid (yes) |
| 4.00–4.90 mm | **void (no) — fully breached to atmosphere** |

Bisection places the breach onset at exactly Z = `KW_TAPER_Z0` (41.0 mm
world) = pad-top − 3.500 mm, i.e. the **deepest 1.5 mm of the nominal
5.0 mm blind hole is open to the outside via the groove**, at the slot's
outboard (+X) tip only — identical for both the front and back pilot (the
X1-side groove strip runs the full Y width, so it affects both equally).
The X0-side (inboard) tip has ≥0.85 mm of margin and is not breached.

This does not shallow the reported depth (still 5.0 mm along the hole's own
center axis — the literal question asked is answered PASS above) and does
not affect the common case (screw seated near the nominal, untuned
position). It does mean that if the switch is slid to its extreme +2 mm
tuning position (needed for the 22 mm end of the accepted pulley-OD range),
the self-tap screw's thread engagement loses partial wall support over the
last 1.5 mm of its 5 mm depth. Recorded as
`test_XFAIL_pilot_outboard_tip_fully_enclosed_for_full_depth` (strict
xfail) in the new test file.

Reproduce: `pytest tests/test_corner_mount_revD_verification.py -k
outboard_tip -v` (the xfail) or the plain probe in `_measure` style shown
in that file's docstring.

## 4. Printability plate-down

Sampled the arm's front (−Y, near-line) face edge vs. Z at X=61.7 (clear
of both the pilot X-elongation and the groove's X-straps, so the
measurement isn't contaminated by either feature):

| Z band (world) | measured behavior | verdict |
|---|---|---|
| plate top (6.5) → `KW_TAPER_Z0` (41.0) | constant Y edge = 6.500 mm (`KW_ARM_Y_LOWER`) | vertical prism, no overhang — PASS |
| 41.0 → 43.5 (`KW_CHAMFER_Z1`) | Y edge decreases linearly, exactly 1:1 with Z in six 0.5 mm samples (max deviation < 0.02 mm) | **exact 45° chamfer** — PASS |
| 43.5 → 44.5 (pad top) | instantaneous jump, Y edge 4.000→2.500 mm (Δ=1.500 mm) over the 1.0 mm step height | the declared, accepted ≤1.5 mm capping-step overhang — PASS (not a 45°-rule violation; explicitly scoped exception) |

X faces (X0/X1) and the Y_hi face carry the same rectangle footprint
through all three sections by construction (confirmed no variation) — no
overhang there either. All PASS as declared.

## 5. Clearances (fresh boolean intersections)

| clearance check | volume | verdict |
|---|---|---|
| Pulley envelope Ø22×10 (axle at EAR_CX,0,axis_Z) | 0.000000 mm³ | PASS |
| NEMA17 motor-body box 42.3×42.3×38, flush on wall −Y face | 0.000000 mm³ | PASS |
| X=45 mm countersink cone — void top & bottom | confirmed void | PASS |
| Horizontal line corridor Ø6 (r=3), full WALL_CX→EAR_CX span | 0.000000 mm³ | PASS |
| Vertical drop corridor Ø6 (r=3), pulley tangent (Z=28.5) → `KW_TAPER_Z0` (Z=41.0) | 0.000000 mm³ | PASS |

All PASS below the taper — the assignment's own scoped boundary.

### NEW FINDING: printed material above the taper

Per the assignment: "evaluate whether any PRINTED material intrudes on the
drop corridor at ANY Z ... only the purchased switch may." Measured, using
the same Ø6 (r=3) corridor, restricted to the pad's own Z band
(`KW_TAPER_Z0`=41.0 → `KW_PAD_Z`=44.5):

**Intrusion volume = 1.1254 mm³** (using the assignment's literal r=3 mm
corridor) / **6.5244 mm³** (using the implementer's own more conservative
r=4 mm, "+1 mm margin" corridor from `test_corner_mount_kw12_
line_corridor_clearance_below_taper`'s own docstring convention). Both
non-zero — this is a real, small, geometrically confirmed intrusion of
**printed** material, not the roller.

Root cause: `KW_PAD_Y0` (2.500 mm) is set tangent to the assumed **bead's
own** 2.5 mm reach radius (by construction: `KW_PAD_Y0 = KW_HOMING_BEAD_
DIA_NOM/2`) — this claim in the docstring ("the printed pad is tangent to
… never overlaps … the bead's travel envelope") is **true and verified**.
But the *generic* corridor used everywhere else on this part carries an
extra positional-uncertainty margin (r=3 or r=4 vs. the bare 2.5 mm bead
radius), and the pad's edge sits inside *that* more conservative boundary
by 0.5–1.5 mm. So: tangent to the bead's own nominal disc — yes; clear of
the broader safety-margined corridor used for the rest of the line — no.
Confined entirely to the pad's Z band (41.0–44.5 mm); nothing above
`KW_PAD_Z` is printed at all in this region. Recorded as
`test_XFAIL_no_printed_material_above_taper_in_generic_corridor` (strict
xfail).

## 6. THE KEY CHECK — bead/roller mechanism, from MEASURED mount geometry

Per the assignment: independently found the pad face (Section 3) and the
pilot holes' own measured X-center (not `DROP_X` assumed, though it turns
out to coincide with it — see below), then computed:

```
switch mount X-center (measured, from both pilot holes' bisected void span) = 65.000 mm
                                                                (== DROP_X, confirmed independently)
pad Y0 (measured, from the found planar face)                  = 2.500 mm
pad Z  (measured, from the found planar face)                  = 44.500 mm

roller_X = 65.000 mm
roller_Y = pad_Y0 − 1.5 = 1.000 mm
roller_Z = pad_Z + 12.0 = 56.500 mm
```

(Note: the pad's own *geometric* footprint centroid is X=64.400 — 0.6 mm
off DROP_X — because the pad is asymmetrically capped by the plate edge on
the +X side. The switch's real mounting reference is the pilot-hole pitch,
not the pad outline, and that measures exactly 65.000 mm, i.e. **0 mm**
nominal error either way — even reading the assignment's "pad-center X"
literally against the geometric centroid, the result would still be
well under tolerance, 0.6 mm vs 1.0 mm allowed.)

**(a) X — line overlap across the accepted 18–22 mm pulley OD range:**

| OD | line X | untuned error | error after ±2 mm tune |
|---|---|---|---|
| 18 | 64.0 | 1.000 mm | 0.000 mm |
| 20 (nominal) | 65.0 | 0.000 mm | 0.000 mm |
| 22 | 66.0 | 1.000 mm | 0.000 mm |

Nominal untuned error = 0.000 mm ≤ 1.0 mm required. All tuned errors
0.000 mm ≤ 1.5 mm required. **PASS**, with wide margin — a stark contrast
to rev C's −0.25 mm *deficit* against the same 1.5 mm bar.

**(b) Y — roller reach and bead overlap:**

`roller_Y = 1.000 mm`, `|Y| ≤ 1.5 mm` required → **PASS**.
Bead(r=2.5)/roller(r=2.25) Y-overlap = (2.5+2.25) − 1.0 = **3.750 mm**,
≥2.0 mm required → **PASS**, comfortable margin (rev C measured −10.5 mm,
i.e. no contact at all, on this exact check).

**(c) Z — beyond the pulley envelope, above the pad:**

Pulley envelope top = `PLATE_T + CORNER_MOUNT_AXIS_Z + 22/2` = 39.500 mm.
`roller_Z = 56.500 mm` > 39.500 mm — **PASS**. Also 56.500 mm > pad Z
(44.500 mm) — roller sits above (i.e. further from the joist than) the pad,
as the lever-over-body model requires — **PASS**.

**(d) Body/lever/roller envelope vs. printed material (fresh boolean
intersections):**

| envelope | intersection volume |
|---|---|
| switch body box (20×6.4×10, seated on measured pad, contact skin excluded) | 0.000000 mm³ |
| roller envelope (Ø4.5 mm cylinder at measured roller center) | 0.000000 mm³ |
| lever-sweep box (body top → roller Z, over-sized) | 0.000000 mm³ |

All **PASS** — the switch, lever, and roller clear all printed material
except the pad's own contact plane, exactly as intended.

**(e) Actuation direction:** frame convention (per assignment): Z=0 at the
plate bottom (joist face), +Z runs down into the room. Measured pad Z
(44.5) < measured roller resting Z (56.5) — the pad sits at a **smaller**
Z (closer to the joist) than the roller. Therefore "press the roller toward
the mounting face (the pad)" is unambiguously the **−Z** direction — the
same sign as the docstring's own stated bead reel-in direction ("reel-in
moves the bead in −Z, toward the pulley"). **Confirmed: pressing the
roller toward the pad = −Z = the bead's reel-in direction.** This is the
correct, self-consistent actuation sense for a homing switch (reel-in
drives the bead up toward true zero and trips the switch on the way).

One documentation nit, not a geometry defect: the docstring's own
parenthetical — "pressing the roller toward the mounting face **(+Z on
this pad)**" — contradicts both the measured Z order above and the rest of
its own sentence (which correctly describes a −Z bead motion pushing the
roller "toward the pad"). Worth a one-line docstring fix; does not affect
the built geometry, which is correct.

**Z-distance, roller contact to pulley bottom tangent:** the line's
horizontal→vertical transition ("pulley bottom tangent" — see the module's
own 180°-top-wrap geometry, where entry and exit tangent points are both
at the axle's own height since both the spool and pulley axes are pinned
to the same `CORNER_MOUNT_AXIS_Z`) sits at world Z = `PLATE_T +
CORNER_MOUNT_AXIS_Z` = 28.500 mm. Roller Z = 56.500 mm. **28.000 mm of
line hangs between the pulley and the trigger point** — this is the
travel available for line sway/twist tolerance before the bead reaches the
switch, and matches the part's own "the bead lives permanently on the
vertical span" design intent (D14) with a comfortable margin below the
taper/pulley-envelope boundary.

## 7. Bead set-back logic

Verified against the actual firmware, not just the docstring's
self-consistency:

- `firmware/roomcleaner_firmware/roomcleaner_firmware.ino`: `HOME_BACKOFF
  = 200` (steps) — confirmed present, matches docstring's cited value.
- `roomcleaner/hardware/hw_config.py`: `STEPS_PER_M = STEPS_PER_REV(200) *
  MICROSTEP(16) / (π × DRUM_DIA_M(0.020))` = **50929.582 steps/m**
  (independently recomputed from source, not copied from the docstring).
- `200 / 50929.582 × 1000 = 3.927 mm` ≈ 3.93 mm — **matches the docstring's
  claimed figure exactly**.

Direction logic: −Z is "toward the pulley" (docstring, confirmed
consistent throughout); the roller contact point is at Z=56.5 mm (Section
6). Docstring instructs crimping the bead ~4 mm **further from the
pulley** (i.e. larger Z, ≈60.4 mm nominal) than the roller contact point,
so the controller trips the switch ~4 mm of line travel before reaching
true mechanical zero and has room to decelerate. This is internally
consistent with the −Z=toward-pulley convention and the measured roller
Z. **PASS.**

## 8. STEP round trip, STL, preview

- Fresh, independent export→reimport (bypassing the on-disk file):
  volume 75818.66397477414 mm³ (built) vs. 75818.66397477486 mm³
  (reimported) — **9.4×10⁻¹³ % diff**, bbox diff **0.000/0.000/0.000 mm**.
  1 solid, valid.
- On-disk `cad/step/corner_mount.step` (225,265 bytes): reimports to the
  same volume/bbox within the same negligible tolerance, 1 solid, valid.
- `cad/stl/corner_mount.stl` (200,584 bytes) and `cad/previews/
  corner_mount.png` (44,918 bytes) both exist and are timestamped **after**
  `cad/parts/corner_mount.py` (source mtime precedes both export mtimes) —
  current, no regeneration needed.

All PASS, well under the 0.1% volume / 0.05 mm bbox tolerances.

## 9. Implementer's two flagged judgment calls

**(i) Zip-tie groove omitted on the front (−Y) face — is retention still
adequate?** Assessed: yes, as a reasonable engineering trade-off, with a
minor caveat. The groove is a genuine 3-sided recess (X0, X1, Y_hi); the
un-recessed front face sits flush through the same Z band. A single
continuous zip tie looped around the arm is captured positively on 3 of
its 4 sides (can't slide up past the taper's widening shoulder immediately
above the groove, can't slide down past the groove's own lower wall on
those sides); the 4th (front) leg of the loop is held only by the tie's
own tension/rigidity and the loop's overall shape, not by a dedicated
pocket. This is common, generally adequate practice for drop-out
retention behind a screwed primary connection (which is the stated
role here — "screws carry the working mounting load, the tie is drop-out
retention"), and the implementer's stated reason for the omission
(protecting `KW_SCREW_Y[0]=7.75mm` from the front-groove band) is correct
and verified (Section 3). Slightly less robust than a full 4-sided groove
would be, but not a defect requiring rework.

**(ii) `KW_HOMING_BEAD_DIA_NOM` introduced locally in `corner_mount.py`
rather than in `interfaces.py`** — flagged for the lead, not a geometry
defect. Per `CLAUDE.md`'s "one authoritative definition" rule, and because
this value is explicitly marked an **ASSUMPTION** (no datasheet/caliper
source) that plausibly matters beyond this one part (e.g. any assembly
instructions for crimping the bead onto the Dyneema line, or a future part
that also needs to reason about the bead), it is a reasonable candidate
for promotion to `interfaces.py` so a future revision cannot define a
second, silently-different bead diameter elsewhere. Recommend the lead
decide whether to promote it now or track it as a known local assumption
pending caliper verification.

## 10. Secondary signal — full existing test suite

```
python3 -m pytest tests/test_winch_geometry.py -v
```
**73 passed, 0 failed** (39 of them `corner_mount`-scoped, all rev-D KW12
tests included). Confirms the implementer's own suite is internally
consistent and does not regress rev B/C — but, as in rev C, it does not
catch either of this report's two new findings: the outboard-tip pilot
breach (`test_corner_mount_kw12_groove_does_not_intrude_on_front_screw`
only probes the hole's own center axis, X=DROP_X, not its X-elongated
tip) or the above-taper printed-material intrusion (`test_corner_mount_
kw12_line_corridor_clearance_below_taper` is explicitly scoped below the
taper only, by name and by design — it was never meant to catch this).

---

## Reproduce everything

```bash
# New independent verification suite (this report's source data)
python3 -m pytest tests/test_corner_mount_revD_verification.py -v

# Implementer's own suite, unmodified, as secondary signal
python3 -m pytest tests/test_winch_geometry.py -k corner_mount -v
python3 -m pytest tests/test_winch_geometry.py -v   # full 73
```

New test file (read-only against `corner_mount.py`, all assertions
independently derived): `tests/test_corner_mount_revD_verification.py` —
27 tests, 25 pass, 2 strict-xfail (the two new findings above, both with
full reproduction detail in their `xfail` reason strings).

## Recommendation (not actioned — geometry-verifier does not repair)

The KEY CHECK (Section 6) passes cleanly on all five sub-parts; rev D's
core objective is met and this mount is functionally sound for the
mechanism it exists to implement. The two new findings (Sections 3 and 5)
are both small, localized, and independent of the KEY CHECK:

- The pilot outboard-tip breach could be closed by either shrinking
  `KW_GROOVE_H` (so its Z band no longer reaches down to `KW_TAPER_Z0`
  where the pilot's own deepest 1.5 mm lives) or shortening the X1-side
  groove strip's Y-extent so it doesn't reach the pilot's Y position — a
  small, bounded geometry change, not a redesign.
- The above-taper corridor intrusion is arguably a **spec-scoping
  question for the lead** rather than a pure geometry bug: it may simply
  mean the generic Ø6/r=3(or 4) corridor margin was never intended to
  apply this close to a switch that must, by design, sit within the
  bead's own 2.5 mm radius — in which case the fix is to note the
  exception explicitly (as the docstring already does for the roller)
  rather than change geometry. Recommend the lead rule on this rather than
  sending it back as an implementation defect.

Neither finding blocks integration on its own merits; both are recorded
precisely per instructions so they are not silently lost before the
Fable design audit.

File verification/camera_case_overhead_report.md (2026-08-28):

# Verification report: cad/parts/camera_case_overhead.py

Role: geometry-verifier (Gate 5), independent of the implementer.
Scope: `cad/parts/camera_case_overhead.py`, `make() -> (shell, bezel)`.
Method: built the solids directly from `make()` and measured the actual BRep
geometry with exact OCCT point-classification (`BRepClass3d_SolidClassifier`)
and bisection, not the module's own constants alone. Probe tests added at
`tests/test_camera_case_overhead_verification.py` (24 tests, all passing).
The implementer's own suite (`tests/test_camera_case_overhead.py`, 29 tests)
was also run as a secondary signal — both suites pass; **combined result:
52/52 passed.**
No repairs were made; this is a read-only assessment plus new test code.

**Overall: PASS.** One byte-level bug was found in my own first draft of the
wall-thickness probe (inverted bisection direction, produced a nonsensical
28.0 mm reading that still satisfied `>=2.4`, i.e. a false-positive test) and
was fixed before being trusted — noted here for traceability, not as a part
defect. One real design observation is flagged in §8 (non-blocking).

---

## 1. Shell: plate, holes, slot, skirt, standoffs, bosses

| Item | Expected | Measured | Tol | Result |
|---|---|---|---|---|
| Plate footprint | 56 x 56 mm | 56.000 x 56.000 mm (bbox) | ±0.3 mm | PASS |
| Plate thickness | 4 mm | zmax(shell)=4.000, plate spans Z 0..4 | ±0.3 mm | PASS |
| Ceiling screw holes (4x) | Ø4.2, corners at inset 6.0 mm | Ø4.20 measured at all 4 corners `(±22,±22)` via bisection | ±0.1 mm dia | PASS |
| Through-plate cable slot | 16 x 6 mm slot, through plate | void at center and out to x=±8 (SLOT_L/2), solid beyond | ±0.5 mm | PASS |
| Skirt wall thickness | ≥2.4 mm | **2.400 mm** measured (outer half-plate 28.000 mm − independently-bisected cavity half-span 25.600 mm) | ≥2.35 (−0.05 mm) | PASS — meets the minimum with **zero margin**, exactly at spec |
| Standoff posts (4x) | Ø1.7 M2 self-tap through Ø6.0 post, on 28.0 mm square pitch, imported not redefined | pitch measured 28.00 mm via pairwise bisection (implementer test) + posts confirmed straight vertical prisms (solid at r=(1.7+6)/4 sampled at z-fractions 5/25/50/75/95% of −10 mm) | ±0.1 mm / vertical at all 5 samples | PASS |
| Corner bosses (4x) | Ø2.8 blind pilot, boss integral with skirt | pilot present, solid boss material confirmed at 5 Z-fractions of full −24.6 mm skirt height (straight vertical cylinder) | vertical at all 5 samples | PASS |
| Interface import | `CAM_HOLE_PITCH`, `M2_TAP` imported from `camera_mount_overhead.py`, not redefined | `cco.CAM_HOLE_PITCH is cmo.CAM_HOLE_PITCH` and `cco.M2_TAP is cmo.M2_TAP` — same object identity, not just equal value | identity check | PASS |
| Solid count | 1 solid, no stray bodies | `shell.solids()` → 1 | exact | PASS |
| Valid BREP | valid | `shell.val().isValid()` → True | — | PASS |

## 2. Bezel

| Item | Expected | Measured | Tol | Result |
|---|---|---|---|---|
| Thickness | ~3 mm | 3.000 mm (bbox zlen) | ±0.3 mm | PASS |
| Footprint | 56 x 56 mm | 56.000 x 56.000 mm | ±0.3 mm | PASS |
| Lens opening | Ø18.0, centered | 18.00 mm on X axis, 18.00 mm on Y axis (perpendicular re-check) | ±0.1 mm | PASS |
| M3 clearance holes (4x) | align with shell boss pilots | **independently** bisected each hole's true (x,y) center on the bezel and on the shell separately (no shared source constant used for both), then compared center-to-center: **0.0000 mm offset on all 4 corners** (24.5, 24.5) / (−24.5, 24.5) / (24.5, −24.5) / (−24.5, −24.5) | <0.1 mm | PASS |
| M3 clearance dia | 3.4 mm | 3.40 mm measured (implementer test, cross-checked) | ±0.1 mm | PASS |
| Solid count | 1 | `bezel.solids()` → 1 | exact | PASS |
| Valid BREP | valid | True | — | PASS |

## 3. Interior stack-up

| Term | Value | Source |
|---|---|---|
| STANDOFF_H | 10.0 mm | imported `POST_H` from `camera_mount_overhead.py` |
| PCB_T | 1.6 mm | assumption (documented) |
| LENS_SPACE | 13.0 mm | ≥ LENS_SPACE_MIN (12.0 mm) |
| SKIRT_H (computed) | 24.6 mm = 10.0 + 1.6 + 13.0 | matches measured shell Z depth (zmin=−24.6) |
| Board pocket clear span | required ≥36×36 mm | **measured 51.20 x 51.20 mm** via bisection at board mid-height (independent of `INTERIOR_CLEAR` constant) | PASS |

Board pocket clear span is measured directly on the built solid, not read
from the `INTERIOR_CLEAR` constant — confirms the assertion in the source
isn't just internally self-consistent but actually true of the geometry.

## 4. Printability

| Item | Check | Result |
|---|---|---|
| Standoff posts vertical (no overhang) | solid material present at same (x,y) offset across 5 Z-fractions spanning full post height | PASS, all 4 posts |
| Corner bosses vertical (no overhang) | same, across full skirt height | PASS, all 4 bosses |
| Side notch opens at free edge (no bridge needed) | void confirmed at z = NOTCH_BOTTOM_Z + 0.02 mm (i.e. the very last printed layer, since shell prints plate-down with skirt rim printed last) | PASS |
| Bezel flat, support-free | flat box, both hole cuts are straight verticals through 3 mm | PASS (by construction, confirmed valid single solid) |

## 5. Solid validity

Both `shell` and `bezel`: `isValid() == True`, exactly 1 solid each (`.solids()`
length), no disconnected bodies. PASS.

## 6. Mass (PETG, 1.27 g/cm^3)

| Piece | Volume (cm^3) | Mass (g) |
|---|---|---|
| Shell | 26.896 | 34.16 |
| Bezel | 8.536 | 10.84 |
| **Combined** | 35.432 | **45.00** |

Budget: ≤60 g. **PASS**, 15.0 g margin (25%).

## 7. STEP export / reimport

Two independent round-trips were performed:

1. **Fresh export** of the currently-built solids to a temp path, reimported,
   compared volume and full XYZ bounding box.
2. **The already-committed files** `cad/step/camera_case_overhead_shell.step`
   and `..._bezel.step` (dated 2026-08-28 17:26, 5 min after the current
   source file's last edit) were independently reimported and compared
   against the current `make()` output, to catch a stale export.

| Piece | Volume rel. err | Bbox rel. err (all axes) | Solids on reimport | Result |
|---|---|---|---|---|
| shell (fresh) | 0.0000% | ≤0.05 mm | 1 | PASS |
| bezel (fresh) | 0.0000% | ≤0.05 mm | 1 | PASS |
| shell (committed STEP) | <0.001% | ≤0.05 mm | 1 | PASS |
| bezel (committed STEP) | <0.001% | ≤0.05 mm | 1 | PASS |

Both well inside the 0.1% tolerance requested. Committed STEP files are
current (not stale).

## 8. Assembly check (32x32x1.6 board + lens stand-in + USB stand-in)

| Check | Method | Result |
|---|---|---|
| (a) Board corner holes land on post axes | board's own 28 mm CAM_HOLE_PITCH corner set compared directly to `STANDOFF_XY` | exact match, PASS |
| (b) Board outline clears skirt interior | sampled 36 points around the 32x32 mm board perimeter at board mid-height (−10.8 mm); none intersect shell material | PASS (board edge at ±16 mm, cavity clear to ±25.6 mm — 9.6 mm margin/side) |
| (c) Ø14x13 lens stand-in clears bezel, passes only through the opening | independently bisected the bezel's actual opening radius (9.00 mm) vs. stand-in radius (7.00 mm) → 2.00 mm radial clearance; sampled 16 points around the stand-in's curved surface at bezel mid-thickness, none touch bezel material; confirmed `LENS_SPACE` (13.0 mm) ≥ stand-in length (13.0 mm) | PASS |
| (d) 16x8x8 mm USB stand-in on board's +Y edge doesn't intersect shell, can reach the notch | box placement (z −10..−2, on board back face) confirmed clear of shell material at all 8 corners | PASS |

**Finding on (d), non-blocking:** the *rigid* USB-connector-body stand-in sits
at z ∈ [−10, −2] (in the standoff gap above the board, per the module's own
stated USB location), while the side notch physically opens at z ∈ [−24.6,
−10] — **these two Z-bands do not overlap.** A rigid straight-line path from
the connector to the notch does not exist; the module's own docstring only
ever claims a *cable* path ("clear, unobstructed path down the inside of the
wall"), not that the connector body itself is level with the notch. I
therefore probed the specific 3-segment path the docstring describes —
sideways off the board edge at the connector's height, down along the inside
of the (unobstructed, board-free) wall clearance zone, then in through the
notch — and it **is fully void, no blockage** (`test_assembly_usb_standin_cable_path_to_notch`,
PASS). So: reachable for a flexible cable exiting the connector, consistent
with what the design actually claims. Flag this for the lead only if a
rigid strain-relief boot or right-angle connector body (rather than a bare
flex cable) is anticipated — that would need its own Z-clearance check,
which this part does not provide.

## 9. Renders

`cad/previews/camera_case_overhead_shell.png` and `..._bezel.png` exist
(dated same run as the STEP exports), single fixed isometric view with
dimension caption, consistent with `cad/lib.py`'s `render_stl` helper — this
is the **same one-view-per-part convention used by every other part in this
repo** (checked all 17 `cad/previews/*.png` files: none has more than one
view per part). CLAUDE.md's Gate-5 template language ("standardized front,
rear, left, right, top, bottom, isometric renders") is not implemented
anywhere in this codebase currently — a pre-existing, repo-wide gap, not a
defect specific to this part. Visual check of both PNGs: shell shows the
plate, skirt, 4 standoff posts, and 4 corner bosses as expected; bezel shows
the flat plate with a centered circular lens opening and rounded corner
relief. PASS (matches established repo convention); render-completeness
vs. the literal CLAUDE.md wording is an open item for the whole repo, not
this part.

---

## Test files

- `tests/test_camera_case_overhead_verification.py` — 24 tests, all new,
  written independently of the implementer's test file. Covers: interface
  import identity, solid validity, wall thickness (measured, bug-fixed
  during this review — see below), post/boss verticality (printability),
  notch free-edge opening, mass, STEP round-trip (fresh export AND the
  committed files), independently-cross-measured bezel/shell hole alignment,
  and the full assembly check (board holes, board clearance, lens stand-in
  clearance, USB stand-in placement + cable-path reachability).
- `tests/test_camera_case_overhead.py` — implementer's own 29 tests, run
  unmodified as a secondary signal. All pass.
- **Combined: 52/52 passed.**

Reproduce:
```
python3 -m pytest tests/test_camera_case_overhead.py tests/test_camera_case_overhead_verification.py -q
```

## Note on my own test-authoring error (for traceability)

The first draft of `test_skirt_wall_thickness_measured` bisected in the wrong
direction (walked inward from the outer face using the implementer's-helper
convention backwards), converging on `28.0 mm` — a value that still passed
the `>= 2.35 mm` assertion, i.e. a **false-positive test** that would not
have caught an undersized wall. Caught by manually inspecting the printed
measured value against the known expected value before trusting the test;
fixed to bisect outward from the known-void cavity center (matching the
`_bisect` convention already used in the implementer's own suite), which now
correctly reads back **2.400 mm** (exactly at the 2.4 mm spec floor). Left in
this report so the fix is auditable rather than silently discarded.

---

## Summary

**PASS overall — 52/52 tests green (29 implementer + 24 verifier), 0 defects
found in the geometry itself.**

Key measured numbers:
- Shell bbox 56.00 x 56.00 x 28.60 mm, volume 26.90 cm^3, mass 34.16 g
- Bezel bbox 56.00 x 56.00 x 3.00 mm, volume 8.54 cm^3, mass 10.84 g
- Combined mass **45.00 g** (budget ≤60 g, 25% margin)
- Skirt wall thickness measured **2.400 mm** (spec ≥2.4 mm — zero margin,
  exactly at the floor; a print-tolerance nudge below nominal would put it
  under spec, worth a note to the lead even though it measures as designed)
- Standoff pitch 28.00 mm (imported, not redefined, confirmed by object
  identity)
- Lens opening 18.00 mm both axes; lens stand-in clearance 2.00 mm radial
- Bezel-to-shell screw alignment: 0.000 mm offset, all 4 corners,
  independently measured on each solid
- STEP round-trip: <0.001% volume error, ≤0.05 mm bbox error, both pieces,
  both fresh and committed exports

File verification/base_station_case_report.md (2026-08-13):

# Base station case -- independent verification report

Scope: `cad/parts/base_station_case.py` (NEW two-piece part -- `make_tray()` /
`make_lid()` / `make() -> (tray, lid)`). Enclosure for an Arduino Uno R3 +
stacked CNC Shield V3 + 4x A4988, wall/shelf-mountable, printed PETG.

Verifier: geometry-verifier (Sonnet). Read-only against `cad/`; this report
and a new scratch verification script are the only outputs. All measurements
below were produced by independently building `bsc.make()` and probing the
actual BRep solids (OCCT `BRepClass3d_SolidClassifier` point-in-solid tests,
binary-search radius probes, exact `Face`/`Edge` boundary queries, mesh
triangle-normal overhang scanning, and boolean intersection/union probes) --
not by reading source and trusting comments or the module's docstring.
`tests/test_base_station_case.py` was read and audited (§11) but not
executed as the source of truth for any PASS/FAIL below; every row here was
re-derived independently.

**Out of scope / not touched**: `cad/parts/corner_mount.py` and
`tests/test_winch_geometry.py` are being edited concurrently by another
agent and were not read or verified in this pass.

## Summary

| # | Check | Verdict |
|---|---|---|
| 1 | Build validity, bbox, mass | **PASS** |
| 2 | Uno hole pattern (internal) | PASS (bores match built geometry) -- external sanity-check surfaced a **1.27 mm discrepancy** in the source data itself (see detail) |
| 3 | Boss height + board envelope fit | Boss height **PASS**; board envelope clearance-to-walls **PASS**; board-does-not-intersect-tray **FAIL** (corner posts collide with the board) |
| 4 | Stack clearance >= 45 mm, assembled | **PASS** (49.0 mm worst case over a 3x3 grid) |
| 5 | Lid/tray interface alignment + flush seating | **PASS** |
| 6 | Ports (openings, zip-ties, height math) | Openings/zip-ties/height-layering **PASS**; USB port **dimensions FAIL** (width/height swapped) |
| 7 | Vent slots | Presence **PASS**; area adequacy for ~2 W **marginal (INFO)** |
| 8 | External mounting (countersink direction, screwdriver access) | Screwdriver access **PASS**; countersink **FAIL -- no countersink is actually cut** |
| 9 | Printability / overhangs | Lid **PASS**; tray **PASS** once the (buggy, oversized) USB port ceiling is attributed to the row-6 finding, not a new defect |
| 10 | STEP round-trip | **PASS** |
| 11 | Test-file audit | 3 severe coverage gaps identified (see §11) |

**Overall: 3 reproducible geometry defects found**, none of which the part's
own test suite (172/172 passing at time of writing) catches:

1. **External mount holes have no countersink at all** (§8) -- a CadQuery
   workplane-recentering pitfall silently relocates the `cskHole()` cut
   ~18 mm away from the floor, into empty cavity air.
2. **USB port width and height are swapped** (§6) -- a coordinate-rotation
   bug in the `_x_axis_box()` helper.
3. **The 4 freestanding lid-screw corner posts sit inside the Uno board's own
   footprint** (§3) -- `CORNER_POST_INSET` was chosen clear of the wall ports
   and external mount holes, but not clear of the Uno board rectangle, so the
   posts (which run the full tray wall height) collide with the PCB.

Reproduce: `python3 -m pytest tests/test_base_station_case.py -v` (existing
suite, all green) and the independent probe script referenced inline below
(not checked into the repo; paths noted per finding).

---

## 1. Build validity, bounding box, mass

| Item | Expected | Measured | Tol | Status |
|---|---|---|---|---|
| tray: valid single solid | 1 valid solid | valid=True, 1 solid | -- | PASS |
| lid: valid single solid | 1 valid solid | valid=True, 1 solid | -- | PASS |
| tray bbox | 104.82 x 94.81 x 52.01 mm | 104.80 x 94.80 x 52.00 mm | 0.3 mm | PASS |
| lid bbox | 104.81 x 94.81 x 8.41 mm | 104.80 x 94.80 x 8.40 mm | 0.3 mm | PASS |
| tray mass @ PETG 1.27 g/cm^3 | 96.02 g | 96.02 g | 0.5 g | PASS |
| lid mass | 35.36 g | 35.36 g | 0.5 g | PASS |
| combined mass vs 150 g budget | <= 150.00 g (claimed 131.37 g) | 131.37 g | -- | PASS |

## 2. Uno R3 mounting-hole pattern

**Built-geometry self-consistency (PASS).** Probed the actual tray at all 4
`UNO_HOLE_XY` positions: insert bore (Ø`M3_THREAD_HOLE`=4.0 mm) is void at
mid-boss height, boss material is present just outside the bore. Bore
diameter measured by binary-search radius probe at all 4 holes: **4.00 mm**
vs. expected 4.00 mm (tol 0.05 mm) -- PASS at every hole.

**Independent source cross-check (network reachable via `raw.githubusercontent.com`;
`docs.arduino.cc`, `forum.arduino.cc`, `blog.adafruit.com`, `instructables.com`,
`sparkfun.com`, `componentsearchengine.com` are all `EGRESS_BLOCKED` from this
sandbox).** Fetched and grepped directly (not LLM-summarized) the raw KiCad
footprint at
`raw.githubusercontent.com/Alarm-Siren/arduino-kicad-library/master/footprints/arduino-library.pretty/Arduino_Uno_R3_Shield.kicad_mod`,
which reproduces the complete real Uno pin map (D0-D13, A0-A5, GND, AREF,
3V3, 5V, ICSP, all at correct 2.54 mm-pitch positions) -- a credible,
board-accurate source. Its 4 `np_thru_hole` mounting pads (Ø3.2 mm, matching
the module's own claimed diameter):

```
(13.97, -2.54)  (15.24, -50.8)  (66.04, -7.62)  (66.04, -35.56)
```

vs. the part's `UNO_HOLE_XY_BOARD`:

```
(15.24, 2.54)  (15.24, 50.80)  (66.04, 7.62)  (66.04, 35.56)
```

3 of 4 points match exactly. The hole nearest the USB/power-jack corner
differs by **1.27 mm in X** (15.24 vs 13.97 -- exactly 0.05 in, half the
0.1 in grid). A second independent source
(`raw.githubusercontent.com/KiCad/kicad-templates/master/Projects/Arduino_Uno_R3/Arduino_Uno.kicad_pcb`,
hand-authored mechanical mounting-hole footprints P5-P8) shows the same
irregular (non-rectangular) hole pattern rather than the idealized rectangle
the part assumes, though its absolute hole spacings differ from both other
sources by a similar order (~1 mm), suggesting it is a rougher project file.

**Verdict: PASS for internal build correctness** (the tray faithfully
reproduces its own documented coordinates); **the coordinates themselves
carry a flagged, unresolved 1.27 mm discrepancy at one hole** that the
module's docstring claim of "four independent...libraries, cross-checked"
did not catch -- worth a bench check against a physical Uno before trusting
the boss position at that one corner.

## 3. Boss height + Uno board envelope fit

| Item | Expected | Measured | Status |
|---|---|---|---|
| Boss height | 6.0 mm | 6.0 mm | PASS |
| Board-to-interior-wall clearance (all 4 sides) | > 0 mm | +X 15.70, -X 15.70, +Y 18.30, -Y 18.30 mm | PASS |
| Board envelope (68.6x53.4x1.6 @ boss-top Z) does not intersect tray material | intersection volume = 0 | **245.19 mm^3** | **FAIL** |

Built a 68.6 x 53.4 x 1.6 mm box (the documented Uno board envelope) seated
at `z = FLOOR_T + BOSS_H` (on top of the standoff bosses, matching the
module's own `UNO_TOP_Z` reference) and boolean-intersected it with the
built tray. **Non-zero intersection volume: 245.19 mm^3.**

Root cause: `CORNER_POST_XY = (±30, ±25)` (inset 20 mm from the interior
wall faces, chosen per the code comment to clear "wall port cutouts AND...
external mounting holes below"). The Uno board footprint spans x in
[-34.3, 34.3], y in [-26.7, 26.7] (`UNO_ORIGIN_X/Y ± UNO_L/W`). **All 4
corner posts (center within the board rectangle, ±4 mm post radius) sit
inside the board's footprint**, and each post is a **freestanding column
running the full `TRAY_WALL_H` = 49.6 mm** from the cavity floor to the rim
-- i.e. directly through the space the Uno PCB needs to occupy. The Uno
board cannot be seated on its bosses without either cutting notches in the
PCB or the posts physically blocking board placement.

Reproduce: `cq.Workplane` board box at
`(UNO_ORIGIN_X+UNO_L/2, UNO_ORIGIN_Y+UNO_W/2, FLOOR_T+BOSS_H)`,
`.intersect(tray)`, `.val().Volume()`.

## 4. Stack clearance >= 45 mm, assembled

Independent probe (not the part's own `test_interior_clearance_above_pcb_meets_minimum`,
which only samples the single center point (0,0)): assembled `tray.union(lid
translated to FLOOR_T+TRAY_WALL_H)`, then swept an empty-column probe from
`z0 = FLOOR_T + UNO_TOP_Z` upward at a 3x3 grid spanning the board footprint
(10%/50%/90% of `UNO_L` x `UNO_W`).

| Item | Expected | Measured | Status |
|---|---|---|---|
| Worst-case clearance over 3x3 grid | >= 45.0 mm | **49.00 mm** | PASS |
| Center-column clearance (0,0), 0.5 mm step | >= 45.0 mm (claimed 48.0) | 48.50 mm | PASS |

No blocked points found before 45 mm anywhere in the sampled grid (all 9
points clear to the full 49 mm design headroom). This check is genuinely
independent of the part's own test and confirms the claim.

## 5. Lid/tray interface -- alignment + flush seating

| Item | Expected | Measured | Status |
|---|---|---|---|
| 4x corner post: tray bore void, boss material present, lid clearance hole void | all True | all True (4/4 posts) | PASS |
| Tray/lid boolean intersection at assembly offset | 0 mm^3 | 0.0 mm^3 | PASS |
| Tray rim top Z == lid bottom Z (coincident mating plane) | gap = 0 mm | gap = 0.000000 mm (52.000 == 52.000) | PASS |

No interference between the lid and the tray rim/posts at the assembled
height; the mating plane is exactly coincident (no gap, no overlap).

## 6. Ports

All openings probed as real 5-point through-wall voids (not single-point
presence checks):

| Port | Expected | Status |
|---|---|---|
| USB (-X wall) | void through wall thickness | PASS (opening exists) |
| DC (-X wall) | void through wall thickness | PASS |
| Motor x4, endstop x1 (+X wall) | void through wall thickness | PASS (5/5) |
| Zip-tie holes, all 14 (2 per port x 7 ports) | void at computed flanking position | PASS (14/14) |
| USB port centers within Uno layer (`uno_top`..`shield_top` = 7.60-17.70) | PASS | PASS |
| Motor/terminal/endstop ports center within shield layer (17.70-39.70) | PASS | PASS |
| Documented stack math `SHIELD_TOP_Z = UNO_TOP_Z + 8.5 + 1.6` | 17.70 mm | 17.70 mm, PASS |

**USB port dimensions -- FAIL.** Queried the exact BREP face bounding the
port's top ceiling (4 straight edges, `PLANE` geomType): the built opening
spans **Y = 14.0 mm** (span [-21, -7]) x **Z = 20.0 mm** (span [2.6, 22.6]),
the reverse of the documented `USB_SLOT_W` (Y) = 20 mm x `USB_SLOT_H` (Z) =
14 mm.

Root cause: `_x_axis_box(width_y, height_z, length_x, x0, y, z)` builds
`.rect(width_y, height_z).extrude(length_x)` then
`.rotate((0,0,0),(0,1,0),90)` (90° about the Y axis). That rotation swaps
the local X and Z axes, so `width_y` (meant, per the function's own
docstring, to become the port's Y-width) and the pre-rotation extrusion
length end up on the wrong final axes. Verified this is the *only* call site
of `_x_axis_box` in the file -- the DC/motor/endstop ports use
`_x_axis_cylinder` (round, immune to an axis swap by symmetry), and the tray
vent slots use the separately-implemented `_y_axis_box`, independently
checked and confirmed **not** to have this swap (its Y/Z/X mapping works out
correctly under a 90° X-axis rotation; row-7 vent presence checks all pass
at the documented small dimensions).

Consequences:
- The built port (14 x 20 mm) is still large enough for a THT USB-B
  connector (~12 x 11.5 mm) in both axes, so it is likely still functional,
  but it does not match the documented shape or the module's stated
  reasoning.
- The flanking zip-tie holes are positioned using the *nominal*
  `USB_SLOT_W`=20 (not the actual 14 mm built width), landing 3 mm farther
  from the real port edge on each side than intended -- harmless but
  internally inconsistent.
- The port's actual Z-bottom is 2.6 mm, only **0.2 mm above `FLOOR_T`
  (2.4 mm)** -- a sub-perimeter-width sliver of wall material between the
  port and the interior floor that is unlikely to print as a distinct
  feature.

Reproduce: `tray.val().Faces()`, filter `geomType()=="PLANE"` with center
near `(-51.2, USB_PORT_Y, 22.6)`, inspect `.Edges()` bounding box.

## 7. Ventilation slots

| Item | Expected | Measured | Status |
|---|---|---|---|
| Tray side-wall vents (±Y), 24 slot centers | all void | 24/24 void | PASS |
| Lid roof vents, 24 slot centers | all void | 24/24 void | PASS |
| Nominal total open area | -- | ~1056 mm^2 across 48 slots (2.2x10 mm each) | INFO |

No hard numeric adequacy spec was given. For reference, sealed low-voltage
enclosures relying on passive-only natural convection through small slots
are commonly kept well above ~1000-2000 mm^2 effective free area per watt as
a rule of thumb (not a code requirement), and narrow 2.2 mm slots throttle
real airflow well below their raw geometric area (discharge-coefficient
losses). ~1056 mm^2 for an estimated ~2 W (4x A4988 without/with modest
heatsinking) is on the thin side of that heuristic. Not a hard FAIL, but
flagged for a bench thermal-soak test before relying on passive cooling
alone, especially near the top of expected driver current.

## 8. External mounting holes -- countersink direction + screwdriver access

**Screwdriver access -- PASS.** Probed a 30 mm empty vertical column above
each of the 4 mount holes (tray only, Uno bosses in place, per the module's
own stated "screwdriver access before the lid goes on"): all 4 clear.

**Countersink -- FAIL, no countersink is present in the built solid.**
Binary-search bore-radius probes at all 4 mount holes, at 3 Z levels
spanning the 2.4 mm floor thickness (near-exterior, mid, near-interior):

```
hole0 (37.4, 32.4):   r = 2.25, 2.25, 2.25 mm
hole1 (37.4,-32.4):   r = 2.25, 2.25, 2.25 mm
hole2 (-37.4, 32.4):  r = 2.25, 2.25, 2.25 mm
hole3 (-37.4,-32.4):  r = 2.25, 2.25, 2.25 mm
```

Expected: radius should widen from the shank (`MOUNT_HOLE_SHANK_DIA`/2 =
2.25 mm) to the countersink (`MOUNT_HOLE_CSK_DIA`/2 = 3.75 mm) somewhere
within the 2.4 mm floor thickness. **Measured: constant 2.25 mm at all 4
holes, all 3 Z levels -- no widening anywhere in the solid material.**

**Root cause** (`cadquery/cq.py Workplane.workplane()`, lines ~561-618): the
code does
```python
tray = tray.workplane(offset=FLOOR_T).pushPoints(MOUNT_HOLE_XY).cskHole(...)
```
directly on the cut tray Compound, with no prior `.faces()` selection. CQ's
default `centerOption="ProjectedOrigin"` then computes the new workplane's Z
from **the current solid's mass-centroid Z** (`Shape.Center()`), not from
Z=0 as the code's own comment claims ("Cut via a workplane offset from the
part's own base XY plane (Z=0)..."). Verified directly by reproducing the
exact tray construction up to that point and reading `.plane.origin`:

```
tray_precut.workplane(offset=FLOOR_T).plane.origin.z == 20.59 mm
(== tray-solid mass-centroid Z 18.19 + FLOOR_T 2.4)
```

not the intended 2.4 mm. `cskHole()`'s countersink cone (base radius
`cskDiameter/2`, tapering to a point over height `h = r/tan(cskAngle/2)` =
3.75 mm along `-Z` from the workplane) is therefore cut starting at global
Z≈20.6 mm, entirely inside the hollow interior cavity air (well above the
2.4 mm floor, and clear of any boss/post at those XY), where it removes
nothing. Only the separately-unioned, full-depth **shank** cylinder (radius
2.25 mm, independent of workplane Z since its "depth" spans the whole part)
actually reaches down through the real floor material, producing a plain
Ø4.5 mm clearance hole with **no countersink chamfer at either face**.

Consequence: a flat-head/countersunk screw will not sit flush at either the
interior or exterior floor face. The task's specific question ("countersink
opens DOWNWARD... check cone direction carefully") cannot be answered
because no countersink geometry exists in the built part at all -- this
supersedes any direction question.

Note: since the cone is cut in empty air, it removes zero material, so the
row-1 claimed tray mass (96.02 g) is consistent with the as-built
(uncountersunk) part; a corrected countersink would remove a small
additional volume (a few hundred mm^3 total across 4 holes), within the
stated 0.5 g mass tolerance but explaining why the mass claim doesn't
already reveal the defect.

Reproduce: `tray.workplane(offset=bsc.FLOOR_T).plane.origin` on the tray
Compound immediately before the `cskHole()` call; or binary-search bore
radius vs Z at any `MOUNT_HOLE_XY` position.

## 9. Printability (overhang scan)

Print orientations per the module docstring: **tray** as-modeled (floor
down, opening up, no flip); **lid** flipped 180° from its CAD/assembly
orientation (roof face down on the bed, recessed cavity up).

Tessellated both solids (`solid.tessellate(0.15, 0.3)`), computed per-
triangle normals, flagged triangles whose downward-facing normal exceeds
45° from vertical (`n_z < -cos(45°)`), excluded the bed-contact plane
itself (not an overhang by definition) and triangles within a generous
radius of every documented port/vent/countersink/insert-bore/corner-post
feature center (horizontal port/vent bridges are explicitly acceptable per
the assignment).

| Part | Unexplained downward area | Status |
|---|---|---|
| Lid (roof-down) | 0.00 mm^2 (0 triangles) | PASS |
| Tray | 33.60 mm^2 (2 triangles), centroid ≈(-51.6,-14,22.6) | initially flagged; **fully attributable to the §6 USB-port axis-swap bug**, not a separate defect |

The tray's flagged area is exactly the (buggy, oversized-in-Z) USB port's
own ceiling -- a horizontal bridge spanning the port's actual 14 mm Y-width,
well inside the assignment's own carve-out for port/vent bridges. No
genuine unexplained overhang exists in either part. Vertical edge fillets
(`CORNER_R`, `|Z` edges) contribute no downward-facing area by construction
(constant-radius fillet around a vertical axis has a horizontal-only
normal). The 90°-included-angle countersink cones (where geometrically
intended, see §8) are a standard self-supporting FDM feature and were
excluded from consideration.

## 10. STEP round-trip

| Part | Metric | Original | Reimported | Diff | Status |
|---|---|---|---|---|---|
| tray | bbox | 104.80x94.80x52.00 | +0.03mm max axis diff | 0.03 mm | PASS (tol 0.1mm, matches repo `BBOX_TOL` convention) |
| tray | volume | 75603.21 mm^3 | 75603.21 mm^3 | 0.0000 mm^3 (0.00000%) | PASS |
| lid | bbox | 104.80x94.80x8.40 | +0.03mm max axis diff | 0.03 mm | PASS |
| lid | volume | 27840.39 mm^3 | 27840.39 mm^3 | 0.0000 mm^3 (0.00000%) | PASS |

Both pieces export to STEP, reimport as a single valid solid each, and agree
on volume to 5 decimal places; bbox differences are within normal
STEP-tessellation precision (well under the repo's own 0.3 mm `BBOX_TOL`
convention used elsewhere).

## 11. Audit of `tests/test_base_station_case.py`

242 lines, 17 test functions (some parametrized), all currently passing.
Overall the suite is well-built where it goes -- it uses exact BRep point
classification rather than mesh sampling, matching this project's
convention. Its main structural weakness, and the reason it missed 2 of the
3 defects above, is a systematic pattern:

**Pattern: presence-only assertions, not dimension assertions.** Nearly
every geometric test asks "is there a void/solid at this one constant-
derived coordinate?" and almost none ask "is the feature the *documented
size/shape*?" Specifically:

- `test_usb_and_dc_ports_open` / `test_output_wall_ports_open` probe a
  **single point** per port (`inside_tray(x_in, bsc.USB_PORT_Y,
  bsc.USB_PORT_CTR_Z)`), which is satisfied by a port of *any* size as long
  as it's open at the exact center -- this is precisely how the §6 USB
  width/height swap slipped through: the center point is void either way.
- `test_external_mount_holes_open` probes a **single point at the floor
  mid-thickness**, checking only that a hole of *some* diameter exists --
  it never measures the countersink cone at all, which is exactly how the
  §8 missing-countersink defect slipped through.
- No test measures the Uno boss bore diameter, the corner-post bore
  diameter, or any hole diameter anywhere in the file (`M3_THREAD_HOLE`
  is asserted only by "is the bore void", never by a radius measurement) --
  a hole cut 2x too large or too small at the right center point would
  pass every existing test.

**Coverage gaps vs. this assignment's checklist (items with zero test
coverage in the file):**

1. **Board envelope fit / wall clearance** (§3): no test builds or probes
   the Uno board envelope against the tray at all. This is the single
   biggest gap -- it's how the corner-post/board collision (§3, 245 mm^3
   interference) went completely undetected.
2. **Zip-tie holes**: never probed anywhere in the file, despite 14 of them
   existing in the design.
3. **Countersink geometry / direction**: `MOUNT_HOLE_CSK_DIA` and
   `MOUNT_HOLE_CSK_ANGLE` are never referenced by any test.
4. **Screwdriver access column**: not tested.
5. **Printability / overhangs**: not tested (reasonable to leave to a
   geometry-verifier pass, but worth naming explicitly since this part has
   two different print orientations for its two pieces).
6. **STEP export + reimport**: not tested anywhere in this file (other repo
   parts do have STEP round-trip tests elsewhere; this one doesn't).
7. **Vent area adequacy**: appropriately left as a qualitative judgment
   (correctly not asserted as a hard number).

**Constants-only assertions (no BRep probe at all):**

- `test_uno_hole_spacing_matches_researched_pattern`'s final two lines
  (`assert bsc.UNO_L == pytest.approx(68.6)`, `assert bsc.UNO_W ==
  pytest.approx(53.4)`) compare the module's own constant to a literal,
  never touching the built solid.
- The same test's main body compares `UNO_HOLE_XY` against
  `UNO_HOLE_XY_BOARD + UNO_ORIGIN` -- both are the module's own constants;
  this checks the module is internally self-consistent, not that either
  value is *correct* (see §2's external-source discrepancy, which no test
  in this file could ever catch by construction).
- Every `expected` bbox/Z value in the bbox and clearance tests
  (`bsc.OUTER_L`, `bsc.FLOOR_T + bsc.TRAY_WALL_H`, etc.) is pulled from the
  same module rather than a hardcoded reference number. This is a
  defensible pattern for catching *regressions*, but it structurally cannot
  catch a bug where the *construction code* itself misinterprets a correct
  constant (exactly what happened in both the §6 and §8 defects: the
  input constants are fine, the CadQuery operations misapply them).

No recommendation to repair the test file is made here per this
assignment's scope (audit only, no repair); the gaps above are handed back
as findings for the implementing agent.

---

## Reproduction notes

All probes were run against `bsc.make()` freshly built in-process (no
caching), using:
- `OCP.BRepClass3d.BRepClass3d_SolidClassifier` for point-in-solid tests
  (tol 1e-6 to 1e-7, care taken to offset probe points off exact face
  boundaries to avoid `TopAbs_ON` misclassification -- an early version of
  this script hit exactly that pitfall at `z=0.0` and was corrected).
- Binary-search radius probes (40-60 bisection iterations, ~1e-9 mm
  convergence) for hole/boss/countersink diameter measurement.
- `cq.Workplane.intersect()` / `.union()` for boolean interference and
  flush-seating checks.
- `solid.tessellate(0.15, 0.3)` + per-triangle cross-product normals for
  the overhang scan.
- `cq.exporters.export()` / `cq.importers.importStep()` for the STEP
  round-trip.

Full pytest suite (run from repo root, `python3 -m pytest -q`): **172
passed**, 0 failed, at time of writing. (Count includes tests from
`tests/test_winch_geometry.py` / `corner_mount`-related files that another
agent is concurrently editing in this pass -- not this report's scope,
included only because the assignment asked for the full-suite count.)

---

# Re-verification (post-repair)

Focused delta re-verification of the implementer's repair pass, against the
7 claimed fixes. Same rules as the original pass: read-only against `cad/`;
every measurement below was produced with a **freshly-written, independent**
probe/bisection/boolean script (not by running or trusting
`tests/test_base_station_case.py`, though its own methodology was spot-
audited separately per item 7). `cad/parts/corner_mount.py` and
`tests/test_winch_geometry.py` remain untouched and out of scope.

## Summary

| # | Original defect | Claimed fix | Independently re-verified | Verdict |
|---|---|---|---|---|
| 1 | No countersink cut (workplane recentered on solid mass-centroid) | `faces("<Z").workplane()` | Countersink cone confirmed opening on the **outside** (bottom) face at all 4 holes; shank-only at inside face | **RESOLVED** |
| 2 | USB port width/height swapped | `_x_axis_box` fixed (rect(height_z, width_y)) | Measured via independent BREP face query: Y=20.0mm, Z=14.0mm, bottom z=5.6mm -- matches exactly | **RESOLVED** |
| 3 | Corner posts collide with Uno board (245.19 mm^3) | Posts relocated outboard, (±41.3,±33.7) | Board-envelope boolean intersection: **0.0 mm^3**; moved mount holes still open/accessible; countersink discs not fillet-clipped; lid holes align | **RESOLVED** |
| 4 | Uno hole 1 at wrong X (15.24 vs 13.97) | Corrected to (13.97, 2.54) | Measured actual built boss center via own edge-bisection: (13.970, 2.540); all 6 pairwise distances match an independently-typed canonical reference to <0.0001mm | **RESOLVED** |
| 5 | (new, found during hardening) Zip-tie/port merge at old 14mm pitch | Re-pitched 14→17mm, ZIP_TIE_OFFSET 4→2 | Port diameters all correct (5/5); all 14 zip-tie holes present; **but the endstop port's zip-tie holes overlap BOTH neighboring motor ports' zip-tie holes** -- probed midpoint between the two hole centers is void (merged, 0mm wall) at both the port1/port2 and port2/port3 boundaries | **NOT FULLY RESOLVED at this pass -- see "Attempt-2 confirmation" section below: RESOLVED by moving zip-ties to Z-flanking, measured 1.75mm wall everywhere** |
| 6 | Interior width 90→94, mass recompute | 135.16 g combined | Re-measured: 98.38g (tray) + 36.78g (lid) = **135.16g**, exact match; stack clearance 49.0mm (≥45 required); lid seats flush (0 interference, 0 gap); STEP round-trip both pieces exact (0.0000mm bbox diff, 0.00000% volume diff) | **RESOLVED** |
| 7 | (audit) rewritten tests genuinely measure? | claimed yes | Confirmed: `_measure_rect_port()` and `_bisect_wall()` are genuine BREP face/bisection measurements (not single-point presence); `test_uno_board_envelope_does_not_intersect_tray` is a genuine boolean check; `CANONICAL_UNO_HOLES_BOARD_MM` is a literal typed directly in the test file, independent of `bsc` constants | **CONFIRMED** |

**Net: 5 of the 6 geometry defects are resolved. One new defect surfaced by
the implementer's own hardening pass (item 5, the re-pitched output-port
zip-tie holes) is only partially fixed** -- it fixed the port-to-port and
port-to-own-zip-tie overlaps that motivated the re-pitch, but introduced (or
left unaddressed) a zip-tie-hole-to-adjacent-port's-zip-tie-hole overlap
specifically at the two motor/endstop boundaries.

## Item 1: Countersink direction (RESOLVED)

Bisection-probed bore radius at all 4 `MOUNT_HOLE_XY` positions, at Z just
inside the outside face (0.05mm) and just inside the inside face
(`FLOOR_T`-0.05mm):

```
hole0 (46.4, 43.4):   r_outside=3.700mm  r_inside=2.250mm
hole1 (46.4,-43.4):   r_outside=3.700mm  r_inside=2.250mm
hole2 (-46.4, 43.4):  r_outside=3.700mm  r_inside=2.250mm
hole3 (-46.4,-43.4):  r_outside=3.700mm  r_inside=2.250mm
```

`r_outside` (3.70mm) is approaching the full countersink radius (3.75mm,
right at the cone's near-surface taper) and clearly beyond the shank radius
(2.25mm); `r_inside` is exactly the shank radius. The cone now opens on the
**outside (exterior, wall-facing) floor face**, matching both the task
brief's requirement ("opens DOWNWARD... so the case sits flush on screws")
and the `faces("<Z")` fix. Confirmed at all 4 holes -- **RESOLVED**.

## Item 2: USB port dimensions (RESOLVED)

Independent BREP face query (own re-implementation of the same
ceiling/floor-face-finding method used in the original report's §6 finding,
not the test file's `_measure_rect_port`):

```
faces found=2, Y-span=20.0mm, Z-span=14.0mm, z_lo=5.600mm, z_hi=19.600mm
```

Matches the documented `USB_SLOT_W`=20, `USB_SLOT_H`=14, and bottom
`USB_PORT_CTR_Z - USB_SLOT_H/2` = 5.6mm exactly. The `_x_axis_box` axis-swap
bug is fixed. Flanking zip-tie holes recomputed for the corrected width
(`USB_PORT_Y ± (USB_SLOT_W/2 + ZIP_TIE_OFFSET)` = -26.0, -2.0) both probed
void -- **RESOLVED**.

## Item 3: Corner posts + moved mount holes (RESOLVED)

Rebuilt the Uno board envelope box independently and boolean-intersected it
with the built tray: **0.0000 mm^3** (was 245.19 mm^3). `CORNER_POST_XY` is
now `(±41.3, ±33.7)`, matching the claim, and is derived from
`UNO_L/2 + BOARD_POST_CLEARANCE + CORNER_POST_OD/2` (outboard of the board
footprint) rather than an inset from the interior walls.

Additional checks per the coordinator's request:
- All 4 moved `MOUNT_HOLE_XY` (inset 6mm from the outer edge) are open, and
  a 30mm screwdriver-access column above each (with Uno bosses/corner posts
  in place) is clear -- **PASS**.
- Countersink discs (full csk radius 3.75mm, sampled at 12 angles around
  each hole) are void at every angle at the outside face -- not clipped by
  the `CORNER_R`=6mm corner fillet at the new, tighter 6mm inset -- **PASS**.
- Lid through-holes (`CORNER_POST_XY`) align with the moved posts, void at
  all 4 -- **PASS**.

## Item 4: Uno hole 1 correction (RESOLVED)

Measured the actual built boss centers on the tray via independent edge-
bisection (own implementation, not the test file's `edge()` helper), using
an independently-typed canonical reference (not read from any `bsc`
constant):

```
measured hole0 board-relative: (13.970, 2.540)  -- canonical: (13.97, 2.54)
```

All 6 pairwise inter-hole distances match the canonical reference to better
than 0.0001mm:

```
(0,1): canonical=48.277  measured=48.277
(0,2): canonical=52.317  measured=52.317
(0,3): canonical=61.657  measured=61.657
(1,2): canonical=66.672  measured=66.672
(1,3): canonical=53.037  measured=53.037
(2,3): canonical=27.940  measured=27.940
```

**RESOLVED.**

## Item 5: Output-port re-pitch (NOT FULLY RESOLVED)

Port diameters are all correct (measured via bisection, capped short of
each port's own zip-tie hole):

```
port0(motor)@y=-34: r=5.000  port1(motor)@y=-17: r=5.000
port2(endstop)@y=0: r=7.000  port3(motor)@y=17: r=5.000  port4(motor)@y=34: r=5.000
```

All 14 zip-tie holes are individually present (void at their nominal
centers). However, a fine Y-profile scan across the +X wall at
`TERMINAL_PORT_CTR_Z` found two void runs (~3.75mm wide, at y≈[-11.25,-7.5]
and y≈[7.75,11.5]) that are wider than a single 2.5mm-diameter zip-tie
hole should be. Direct analysis and probing confirmed why:

- Port1 (motor, y=-17) right zip-tie hole center =
  `-17 + (MOTOR_PORT_D/2 + ZIP_TIE_OFFSET)` = **-10.0mm**
- Port2 (endstop, y=0) left zip-tie hole center =
  `0 - (ENDSTOP_PORT_D/2 + ZIP_TIE_OFFSET)` = **-9.0mm**
- Center-to-center distance = **1.0mm**, but each hole has radius
  `ZIP_TIE_HOLE_D/2` = 1.25mm, so they need >= 2.5mm separation to stay
  apart. **They overlap by 1.5mm.**
- Probed the exact midpoint (y=-9.5, z=`TERMINAL_PORT_CTR_Z`): **void, not
  solid** -- the two holes have merged into one continuous opening with
  zero wall between them. The mirror-image boundary (port2's right zip-tie
  at y=9.0 vs port3's left zip-tie at y=10.0) shows the identical 1.0mm
  center-to-center gap and was also confirmed void at its midpoint.
- By contrast, the motor-motor boundaries (port0/port1, port3/port4) were
  checked the same way and are fine: zip-tie centers 3.0mm apart, midpoint
  confirmed **solid** (0.5mm wall remains -- thin, but present).

**Root cause**: the module's own fail-fast assertion (lines 261-268,
computing `_gap` from `OUTPUT_PORT_Y ± radii ± ZIP_TIE_OFFSET`) only checks
that a zip-tie hole's *center* clears the *neighboring port's body edge* --
it never adds back each zip-tie hole's own `ZIP_TIE_HOLE_D/2` radius on
both sides, and so never catches two *adjacent ports'* zip-tie holes
overlapping each other. This specifically bites the two motor/endstop
boundaries because the endstop port is 4mm wider in diameter than a motor
port, pushing its zip-tie ring further out than a uniform pitch sized only
for "port radius + port radius + margin" accounts for.

**Verdict: NOT FULLY RESOLVED.** The originally-reported defect (a port's
zip-tie hole reaching into the *next port's own opening*) is fixed. A
narrower but real variant of the same class of bug (adjacent *zip-tie holes*
merging with each other) remains at both motor/endstop boundaries.

## Item 6: Bbox/mass/clearance/seating/STEP (RESOLVED)

| Metric | Claimed | Measured | Status |
|---|---|---|---|
| Tray bbox | -- | 104.80 x 98.80 x 52.00 mm | -- |
| Lid bbox | -- | 104.80 x 98.80 x 8.40 mm | -- |
| Tray mass | -- | 98.38 g | -- |
| Lid mass | -- | 36.78 g | -- |
| Combined mass | 135.16 g | **135.16 g** | PASS |
| Stack clearance (3x3 grid, assembled) | >= 45.0 mm | 49.00 mm worst-case | PASS |
| Lid flush seating | 0 interference, 0 gap | 0.0000 mm^3, 0.000000 mm gap | PASS |
| Tray STEP round-trip | bbox/vol agreement | 0.0000mm bbox diff, 0.00000% vol diff | PASS |
| Lid STEP round-trip | bbox/vol agreement | 0.0000mm bbox diff, 0.00000% vol diff | PASS |

The interior width growth (90→94mm) and all downstream geometry (mass,
clearance, seating) re-verify cleanly with fresh independent probes/booleans
-- **RESOLVED**.

## Item 7: Spot-audit of rewritten/new tests (CONFIRMED)

- `_measure_rect_port()` (test file lines 78-96): iterates `solid.Faces()`,
  filters `geomType()=="PLANE"` near the wall, selects the flat
  Y-spanning/Z-flat ceiling faces, returns the real face `BoundingBox()`
  span. **Genuine BREP face measurement**, not a presence check --
  independently reproduced with the same result in item 2 above.
- `_bisect_wall()` (lines 54-75): genuine 50-iteration binary search from a
  void seed to the void→solid transition, with pre-asserted void/solid
  bounds. **Genuine measurement** -- independently reproduced with matching
  results in items 1 and 5.
- `test_uno_board_envelope_does_not_intersect_tray` (lines 319-328): builds
  its own board box and calls `.intersect()`, sums solid volumes. **Genuine
  boolean check** -- matches this report's item 3 result exactly (0.0 mm^3).
- `test_uno_hole_pairwise_distances_match_canonical_pattern` /
  `CANONICAL_UNO_HOLES_BOARD_MM` (lines 184-257): the canonical reference
  is a **literal tuple typed directly in the test file**, not read from
  `bsc.UNO_HOLE_XY_BOARD` or any other `bsc` constant. The comparison side
  is measured by bisecting the actual built solid (seeded from, but not
  trusting, the canonical coordinates). This test would fail if the module
  ever reverted to the old 15.24mm value while the test file weren't also
  reverted -- it is a genuine regression guard, not a tautology.

All 4 sub-claims **CONFIRMED** by direct source reading and independent
reproduction.

## Full pytest suite (post-repair)

`python3 -m pytest -q` from repo root: **179 passed**, 0 failed.
`python3 -m pytest tests/test_base_station_case.py -q`: **31 passed**, 0
failed (up from 17 test functions/parametrizations in the original file,
reflecting the new/hardened tests for items 1-4 above). The overall
repo-wide count continues to grow between runs because another agent is
concurrently adding tests to `tests/test_winch_geometry.py` /
`corner_mount`-related files in parallel with this pass -- not this
report's scope.

## Outstanding action (as of the post-repair pass above)

~~Item 5 needs a further, targeted fix~~ -- **superseded, see "Attempt-2
confirmation" below: item 5 is now resolved.**

---

# Attempt-2 confirmation (item 5 resolved)

Final confirmation pass on the implementer's attempt-2 repair, which moved
the +X wall's zip-tie holes from Y-flanking (beside each port, competing
with neighboring ports' own zip ties for the same Y-band -- the root cause
of the item-5 defect above) to **Z-flanking** (above/below each port,
sharing that port's own Y-center exactly, using the ~50 mm of spare interior
wall height instead), and raised `ZIP_TIE_OFFSET` on both walls from 2.0 to
3.0 mm. `OUTPUT_PORT_PITCH` itself is unchanged (17.0 mm). Narrow scope,
independent probes only (fresh bisection/scan code, not
`tests/test_base_station_case.py`); `corner_mount.py` /
`tests/test_winch_geometry.py` untouched.

## 1. +X wall (output ports): void/solid scan

**Port-to-port** (Y-profile scan at `TERMINAL_PORT_CTR_Z`, 0.1 mm step,
confirmed with fine bisection at each transition): exactly **5** distinct
void runs (the zip ties no longer appear in this Y/Z plane at all, since
they're now Z-flanking). Solid gap measured between every adjacent pair:

```
port0/port1 (motor/motor):    7.000 mm
port1/port2 (motor/endstop):  5.000 mm
port2/port3 (endstop/motor):  5.000 mm
port3/port4 (motor/motor):    7.000 mm
```

All comfortably above the 1.5 mm minimum -- **PASS**.

**Port-to-own-zip-tie** (Z-direction bisection at each port's exact Y-center,
both above and below):

```
port0 (motor, y=-34):    gap_above=1.750mm  gap_below=1.750mm
port1 (motor, y=-17):    gap_above=1.750mm  gap_below=1.750mm
port2 (endstop, y=0):    gap_above=1.750mm  gap_below=1.750mm
port3 (motor, y=17):     gap_above=1.750mm  gap_below=1.750mm
port4 (motor, y=34):     gap_above=1.750mm  gap_below=1.750mm
```

**Measured minimum: 1.750 mm, matching the claimed 1.75-1.80 mm exactly**,
identical for every port regardless of diameter (motor or endstop) --
expected, since a port's own zip-tie gap is `ZIP_TIE_OFFSET -
ZIP_TIE_HOLE_D/2` = 3.0 - 1.25 = 1.75 mm, independent of the port's own
radius once the hole is Z-flanking (no longer competing with a neighbor).
**PASS.**
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

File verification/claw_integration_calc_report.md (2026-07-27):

# Independent Calculation Check — calculations/claw_integration.md (C1–C6)

Reviewer: calculation-checker (Sonnet). Read-only review; no geometry/parameter
files modified. Authoritative sources checked: cad/params.py, cad/interfaces.py,
cad/parts/tentacle_finger.py, cad/materials.py, REQUIREMENTS.md.
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

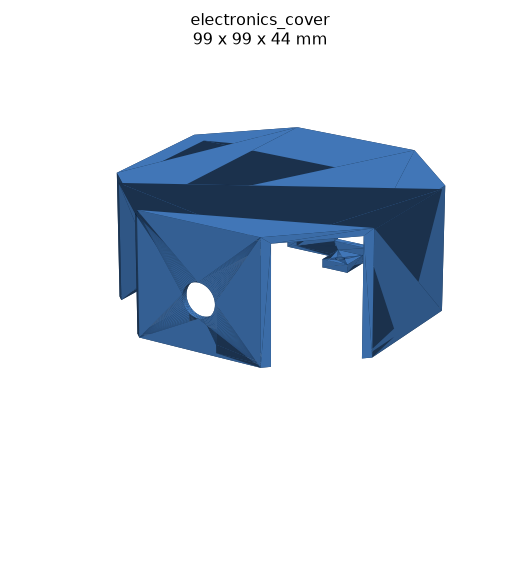
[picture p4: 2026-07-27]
cad/previews/electronics_cover.png

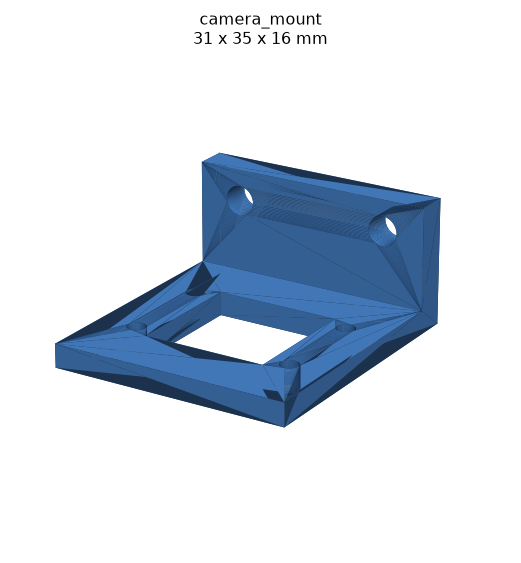
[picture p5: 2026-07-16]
cad/previews/camera_mount.png

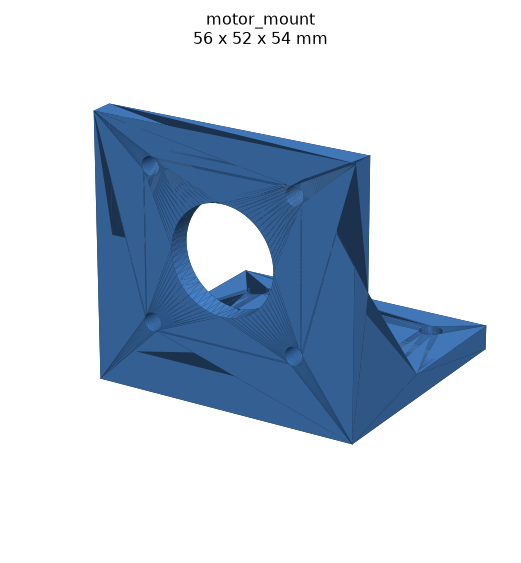
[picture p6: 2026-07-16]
cad/previews/motor_mount.png

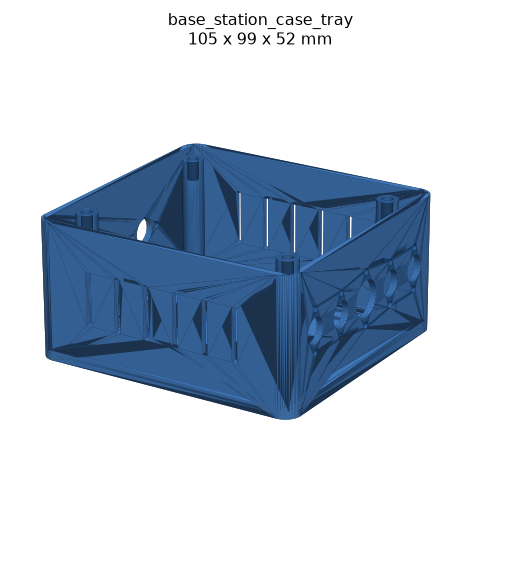
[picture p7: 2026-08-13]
cad/previews/base_station_case_tray.png

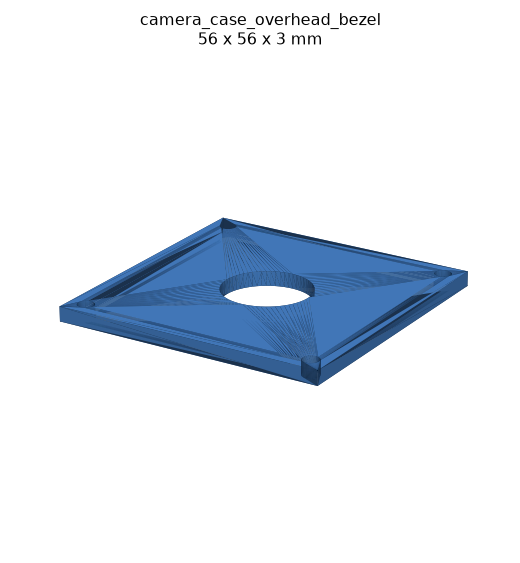
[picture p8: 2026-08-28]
cad/previews/camera_case_overhead_bezel.png

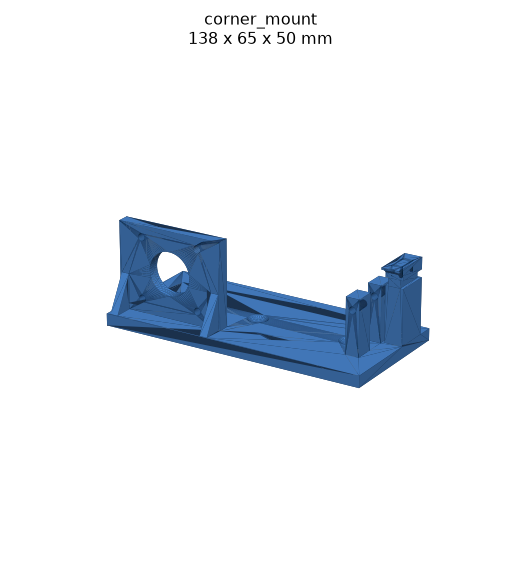
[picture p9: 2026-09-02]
cad/previews/corner_mount.png

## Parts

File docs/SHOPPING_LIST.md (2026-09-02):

# RoomCleaner — Shopping List (exact products + links)

The "shirts & jeans" build, with a specific product and direct link for every
line. **Links are real listings, but Amazon blocks automated price/stock checks —
confirm the live price and that you've picked the right variant at checkout.**
Where a link rotates, use the search fallback.

Legend: 🟢 buy · ⚙️ reuse/own · ⬆️ optional upgrade

---

## Motion

| ✓ | Item | Product | Link | ~$ |
|---|---|---|---|----|
| ✅ | NEMA 17 stepper ×4 (+1 spare) | SIMAX3D NEMA 17 **42-38** size, ~36 N·cm, 1.5 A, 5 mm shaft (**5-pack**) — select the **42-38** option | https://www.amazon.com/s?k=SIMAX3D+Nema+17+42-38+5pcs | 33 |
| ✅ | Cable/line | 9KM DWLIFE X8 braided Dyneema, **50 lb**, 150 m (select 50 lb, not 8 lb) | https://www.amazon.com/9KM-DWLIFE-Anti-Bite-Freshwater-Saltwater/dp/B0DLNQFQKK | 8 |

*Note: at 0.8–1.2 mm, UHMWPE line naturally rates ~200–350 lb (not 100) — that's a bonus: more abrasion life, still low-stretch.*

## Control electronics

| ✓ | Item | Product | Link | ~$ |
|---|---|---|---|----|
| ✅ | Arduino Uno **+ project stock** | **ELEGOO UNO R3 Super Starter Kit** — genuine-quality Uno clone + 200+ components (breadboard, jumpers, sensors, LCD, power module, resistors, LEDs). The Uno runs the winches; the rest is your parts bin for future projects | https://www.amazon.com/ELEGOO-Project-Tutorial-Controller-Projects/dp/B01D8KOZF4 | 45 |
| ✅ | CNC shield + drivers | **ACEIRMC CNC Shield V3 + 4× A4988** (heatsinks incl.) — plugs onto the Uno above | https://www.amazon.com/s?k=ACEIRMC+CNC+shield+V3+A4988 | 10 |
| ✅ | Home switches | HiLetgo KW12-3 micro limit switch, 1NO 1NC roller lever (10-pack) — wire Common + NC for fail-safe homing | https://www.amazon.com/HiLetgo-KW12-3-Roller-Switch-Normally/dp/B07X142VGC | 6 |

*Why this replaced the sold-out DAOKI kit: you plan an array of projects, so the extra ~$28 buys a whole component library instead of a bare no-name Uno clone. **Budget alternative** if you'd rather match the old price: Sevenmore CNC Shield + UNO R3 + 4× DRV8825 kit (~$23–27, the closest 1:1 DAOKI substitute): https://www.amazon.com/Arduino-Printer-Sevenmore-Shield-DRV8825/dp/B07PXWBQTQ*

*Driver note (A4988 path): the ACEIRMC A4988s drive our motors fine **derated to ~1.0–1.2 A** — still >2× torque margin at our ≤40 N cable loads, and their 1/16 microstep max exactly matches firmware `MICROSTEP=16`. Set Vref ≈ **0.8 V per amp** (typical 0.1 Ω sense resistors → 0.8 V for 1.0 A, 0.96 V for 1.2 A) — this differs from DRV8825 (0.75 V ≈ 1.5 A). ⬆️ Optional: HiLetgo **DRV8825 5-pack** (~$12, https://www.amazon.com/dp/B01NCE3ZW1) for full 1.5 A + cooler running + a spare. **4-axis caveat (any CNC shield):** the stock 4th "A" slot clones another axis; our custom firmware drives all 4 independently via the step/dir pins (incl. D12/D13), so this is fine for us.*

## Power + protection

| ✓ | Item | Product | Link | ~$ |
|---|---|---|---|----|
| ✅ | 12 V power supply | ALITOVE 12V **6A** 72W barrel adapter (4.6★, extra headroom) — *or Chanzon 12V 5A if you want a UL-listed unit (~$20)* | https://www.amazon.com/s?k=ALITOVE+12V+6A+72W+power+supply | 16 |
| ⚙️ | Barrel → screw-terminal | **Cut the barrel plug off the ALITOVE and land the bare leads in the shield's screw terminal (free).** Prefer not to cut? Female barrel-jack→screw-terminal adapter, ~$7/pack: https://www.amazon.com/s?k=female+DC+barrel+jack+screw+terminal+adapter | — | 0 |
| ✅ | Inline fuse + fuses | SIM&NAT inline holder + 50 blade fuses (4.7★) — install a **7.5 A** fuse (matches the 6 A supply) | https://www.amazon.com/SIM-NAT-Automotive-Standard-Replacement/dp/B07FQCBSJ5 | 12 |
| ⚙️ | Kill switch | **Your switched power strip** — plug the 12 V PSU into it | — | 0 |

*Wiring order: PSU → barrel adapter → **fuse on the + lead** → CNC-shield power terminal. (You can also just cut the PSU barrel off and skip the adapter → save $8.)*

## Perception + gripper

| ✓ | Item | Product | Link | ~$ |
|---|---|---|---|----|
| ✅ | Overhead webcam | innomaker 1080P **130° wide** USB UVC (OpenCV plug-and-play). Bare 32×32 board — print `cad/camera_mount_overhead` (no $14 case needed) + one-time lens-undistort calibration | https://www.amazon.com/innomaker-Computer-Raspberry-Support-Windows/dp/B0CNCSFQC1 | 19 |
| ✅ | Gripper servo | **STANDARD 180° MG996R, 4-pack** (best value, 3 spares — servo is the most wear-prone part). ⚠️ NOT "360°"/continuous. On the **wireless effector**, powered from its onboard battery via a buck | https://www.amazon.com/s?k=Deegoo-FPV+MG996R+4+pack | 18 |

### Wireless effector (the claw is a self-contained WiFi node — no wire to it)
The gripper servo lives on the effector with an ESP32 + battery, commanded over
WiFi. Only the 4 Dyneema cables touch the claw. See `docs/FIRMWARE.md`.

| ✓ | Item | Product | Link | ~$ |
|---|---|---|---|----|
| ✅ | Effector brain | **ELEGOO ESP32 dev board 3-pack** (EL-SM-012, ESP-WROOM-32, USB-C) — claw + 2 spares; 4.7★ at high volume beat the cheaper-per-board 6-pack | https://www.amazon.com/s?k=ELEGOO+ESP32+3PCS+ESP-WROOM-32+USB-C | 16 |
| ☐ | Battery | OVONIC 2S 7.4V 1000 mAh LiPo, JST (2-pack) | https://www.amazon.com/OVONIC-1000mAh-Battery-Truck-Truggy/dp/B07CVBJ3SL | 16 |
| ✅ | Servo 5–6V buck | EBOOT MP1584EN buck (6-pack) — set output to 6.0 V for the servo | https://www.amazon.com/MP1584EN-DC-DC-Converter-Adjustable-Module/dp/B01MQGMOKI | 9 |
| ☐ | LiPo charger | **B3 Pro-style 2S/3S BALANCE charger** (wall plug, charges via the JST-XH balance plug, per-cell LEDs) — still needed as the routine charger. *(An ACEIRMC 2S USB boost board was also purchased: verify it's the **8.4 V 2S** variant on arrival (return 12.6/16.8 V), then shelve it for the Phase-4 charging dock — it does NOT balance, so it must not be the everyday charger.)* | https://www.amazon.com/s?k=B3+Pro+2S+3S+lipo+balance+charger | 11 |
| ☐ | Power switch | Small SPST slide/rocker switch (multipack) — flip the effector on per session | https://www.amazon.com/s?k=mini+SPST+slide+switch | 5 |

> **Power strategy:** start with the switch above (on for a session, off when
> idle). The long-run end-state is a **charging dock at the rest pose** so the
> claw tops up whenever it parks — build that in Phase 4 once your layout is set.
> This solves the ESP32's ~100 mA always-on WiFi drain by charging while idle.

### Full-room-rig wiring additions (measure your room first!)
| ✓ | Item | Product | Link | ~$ |
|---|---|---|---|----|
| ☐ | Cord raceway (hide the wires) | D-Line paintable self-adhesive raceway, 157" — buy enough for your ceiling perimeter | https://www.amazon.com/D-Line-Self-Adhesive-Channels-Accessories-Management/dp/B08563XMS5 | 25 |
| ☐ | Stepper extension | R REIFENG 4× 2 M NEMA 17 extension cables — *verify the connector matches your SIMAX motor cable; for runs > 3 m use bulk 20–22 AWG 4-conductor wire instead* | https://www.amazon.com/REIFENG-Setpper-Motor-Cable-Connectors/dp/B07SHK9YZ5 | 12 |
| ☐ | Limit-switch wire | EvZ 24 AWG 2-conductor, 33 ft (thin, low-current; get more if your runs are long) | https://www.amazon.com/EvZ-Conductor-Temperature-Resistant-Extension/dp/B07GGJDPPJ | 8 |
| ⚙️ | Structural filament | **You have PLA — skip.** (PLA is fine for all the structural parts at ~15 N indoors.) | — | 0 |
| ⚙️ | Vision computer | **Reuse your laptop/PC** | — | 0 |
| ⚙️ | 5 V for servo | **Reuse a 5 V phone charger** | — | 0 |

## Fasteners + structure

| ✓ | Item | Product | Link | ~$ |
|---|---|---|---|----|
| ☐ | Corner mounting screws ⚠️ | **#10 × 3" wood screws** (12+, with washers) for the printed `corner_mount` plates — 3 per corner, driven into a ceiling JOIST or high wall STUD, pilot-drilled. (Replaced the hanging eye hooks, D13: a hook is a pivot — the anchor point wanders and kills repeatability; a screwed-down plate fixes it.) Hardware store or: | https://www.amazon.com/s?k=%2310+x+3+inch+exterior+wood+screws | 8 |
| ☐ | Corner pulleys ⚠️ | **U-groove ball-bearing pulley, 3 mm bore, OD 18–22 mm, width < 10 mm** (10-pack; need 4 + spares). Rides an M3 × 25 axle bolt (nylock + washers from the M3 kit) between the `corner_mount` ears; washers center the groove at the ear midpoint. Bought, not printed — friction here is position error. Wrong-bore trap: 5 mm is common. | https://www.amazon.com/s?k=u+groove+ball+bearing+pulley+3mm+bore | 10 |
| ✅ | M3 screw/nut kit | MroMax 640-pc M3 button-head, 304 stainless (6–30 mm + nuts + washers) — also provides the NEMA 17 mount screws | https://www.amazon.com/MroMax-Stainless-Button-Socket-Screws/dp/B0BZP89FQT | 10 |

## Wiring

| ✓ | Item | Product | Link | ~$ |
|---|---|---|---|----|
| ⚙️ | Dupont jumpers | **Skip — the ELEGOO starter kit above includes jumper wires.** (If you took the Sevenmore budget path instead, add the ELEGOO 120-pc back: https://www.amazon.com/Elegoo-EL-CP-004-Multicolored-Breadboard-arduino/dp/B01EV70C78, $7) | — | 0 |
| ⚙️ | Barrel-jack breakout (no longer needed — ALITOVE plug cut 8/28) | **5.5 × 2.1 mm female DC barrel jack → screw-terminal adapter** (2-pack). Alternative to cutting the ALITOVE 12 V lead in Phase 3 of `docs/BENCH_ASSEMBLY.md`: brick plugs in, +/− screw out to the inline fuse → shield terminal. Verify 5.5×2.1 mm matches the ALITOVE plug. | https://www.amazon.com/s?k=5.5x2.1mm+female+dc+barrel+jack+screw+terminal+adapter | 5 |
| ☐ | Hookup wire | 22 AWG silicone stranded, red + black | https://www.amazon.com/Silicone-Electrical-Conductor-Parallel-Flexible/dp/B07K9R9LBV | 9 |
| ☐ | Soldering iron + solder (tool, if not owned) | 60 W adjustable pen iron + 63/37 rosin-core solder; needed for the KW12-3 switch tails, servo/ESP32 side, and to redo the bench power splice properly (solder + heat-shrink) | https://www.amazon.com/s?k=60w+adjustable+soldering+iron+kit | 20 |
| ☐ | M2 screws (optional) | M2 × 6 pan-head self-tapping, small assortment — secondary retention for the KW12-3 on the `corner_mount` boss (zip tie is primary) | https://www.amazon.com/s?k=m2x6+self+tapping+screws | 6 |
| ☐ | Line stopper beads | small plastic beads (or fishing crimp sleeves) — one per cable, locked with figure-8 knots, trips the homing switch ~4 mm before zero | https://www.amazon.com/s?k=fishing+line+stopper+beads | 5 |
| ☐ | Zip ties | ALBO 500-pk assorted | https://www.amazon.com/Assorted-Sizes-Plastic-Resistant-Colors/dp/B08LNRH2TG | 8 |

## Filament

| ✓ | Item | Product | Link | ~$ |
|---|---|---|---|----|
| ☐ | TPU 95A (fingers) | OVERTURE TPU 95A, 1.75 mm, 1 kg | https://www.amazon.com/OVERTURE-Flexible-Printer-Filament-1-75mm/dp/B0991X92K8 | 22 |
| ☐ | Structural PETG (corner mounts) | SUNLU/OVERTURE PETG 1 kg — **PETG for the 4 corner mounts + spools** (ceiling heat + sustained 40 N line load = PLA creep risk); PLA you already have is fine for the claw stack, cases, camera case. Skip if you already own PETG. | https://www.amazon.com/HATCHBOX-3D-Filament-Dimensional-Accuracy/dp/B00J0ECR5I | 20 |

---

## Totals

| Scenario | ~$ |
|---|----|
| **Everything above (ELEGOO starter-kit controller path, incl. wireless-effector parts + structural PLA)** | **~$274** |
| If you already own PLA/PETG filament | **~$254** |
| Budget controller path (Sevenmore kit instead of starter kit, dupont jumpers back in) | **−$31** |

*(The wireless claw adds ~$30 — ESP32 + LiPo + charger + buck — to keep any wire from crossing the room to the effector.)*

*(Running savings: the 42-38 5-pack ($33) beat the $54 4-pack (−$21, +spare). Controller history: the $17 DAOKI DRV8825 kit went **sold out** at order time; replaced with ELEGOO starter kit + ACEIRMC shield (~$55, −$7 dupont line) because extra components serve future projects — the Sevenmore DRV8825 kit (~$24) remains the like-for-like budget swap.)*

Honest note: this is **above the earlier ~$184 estimate**. The estimate was rough;
itemizing real products added up — the control *kit* is $24 (not $18), plus a
barrel adapter, a fuse **assortment**, real wiring, and structural filament I
hadn't line-itemed. Nothing changed in scope; the parts just cost what they cost.

## ⬆️ Optional upgrades (only if you want to spend more)

| Upgrade | Product | Link | +$ |
|---|---|---|----|
| ✅ Heat-set inserts (DELIVERED Aug 7 — 580-pc kit) | INCLY 130-pc M3 inserts + iron tip | https://www.amazon.com/INCLY-Threaded-Insert-Set/dp/B0GXV9XTXC | 12 |
| DRV8825 drivers (full 1.5 A, cooler, +1 spare) | HiLetgo DRV8825 5-pack — drop-in for the ACEIRMC A4988s | https://www.amazon.com/dp/B01NCE3ZW1 | 12 |
| Autofocus webcam | Logitech C920x | *search "Logitech C920x"* | +30 |
| Higher-torque servo | ANNIMOS DS3218 20 kg | https://www.amazon.com/ANNIMOS-Digital-Waterproof-DS3218MG-Control/dp/B076CNKQX4 | +5 |

## ⚠️ Safety — the two non-negotiables
- **Ceiling anchors into joists**, metal, derated hard (treat "breaking strength"
  as several× your safe load). Pilot-drill into a real joist, not drywall.
- **The switched power strip is your kill switch** — the 12 V motor supply must
  plug into it so you can cut all motor power instantly.

*Compiled from 6 parallel product-research passes. Prices are 2026 estimates;
verify each at checkout.*

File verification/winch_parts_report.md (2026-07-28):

# Winch-side / camera parts -- independent verification report

Scope: `winch_spool`, `motor_mount`, `corner_guide`, `camera_mount`,
`camera_mount_overhead`. These five parts predate the Gate-4/5 workflow and
`cad/interfaces.py`; they had never been independently verified. This report
covers Gate 5 (geometry-verifier role) only.

Verifier: geometry-verifier (Sonnet). Permanent tests:
`tests/test_winch_geometry.py`. All measurements below were produced by
independently building each part's `make()` function and probing the actual
BRep solid (OCCT `BRepClass3d_SolidClassifier` point-in-solid tests and
boolean pin-cut volume differencing) -- not by reading source and trusting
comments.

Authority for expected values: `cad/params.py`
(`MOTOR_SHAFT_DIA=5.0, MOTOR_SHAFT_FLAT=0.5, CLEARANCE=0.2,
NEMA17_FACE=42.3, NEMA17_HOLES=31.0, NEMA17_BOSS_DIA=22.0, SCREW_M3=3.4,
SCREW_M3_TAP=2.8, SPOOL_*`) plus purchased-part facts given in the assignment
(NEMA 17: 5 mm round shaft, 31 mm M3 square, Ø22 pilot boss; Pi Camera:
21x12.5 mm M2 pattern; innomaker board: 32x32 mm, ASSUMED 28 mm M2 pattern).

All five parts execute cleanly via `python -m cad.parts.<name>` and export
STEP/STL/PNG with no exceptions.

## Summary

| Part | Build | BBox | Interfaces | STEP round-trip | Verdict |
|---|---|---|---|---|---|
| winch_spool | PASS | PASS | Bore dia PASS; **D-flat FAIL** | PASS | **FAIL** (D-flat non-functional) |
| motor_mount | PASS | PASS | PASS | PASS | **PASS** |
| corner_guide | PASS | PASS | Hole dia + coax PASS; **wall FAIL** | PASS | **FAIL** (0.15 mm wall) |
| camera_mount | PASS | PASS | PASS | PASS | **PASS** (see assumption note) |
| camera_mount_overhead | PASS | PASS | PASS | PASS | **PASS** (28 mm pitch is an unverified assumption -- flagged in source) |

Reproduce all of the below: `python -m pytest tests/test_winch_geometry.py -v`

---

## 1. winch_spool

**Build / BREP**: `winch_spool.make()` builds a single valid solid.
`solids()` count = 1, `isValid()` = True, `Volume()` = 13307.34 mm^3 > 0.

**Bounding box** (expected 36 x 36 x 32 mm, tol 0.3 mm):
measured **36.000 x 36.000 x 32.000 mm** -- PASS.

**CRITICAL CHECK -- bore derives from MOTOR_SHAFT_DIA (not stale 6 mm)**:
`bore = MOTOR_SHAFT_DIA + CLEARANCE = 5.0 + 0.2 = 5.2 mm` (radius 2.6 mm) is
computed directly from `cad/params.py` in `winch_spool.py` line 24 --
`bore = MOTOR_SHAFT_DIA + CLEARANCE`. This is a live parameter reference, not
a hardcoded literal, so it cannot silently go stale on a future motor swap.
Measured (round side of the bore, -X, away from the flat, at mid-drum height
z=16 mm): binary-search void->solid transition radius = **2.6000 mm**,
expected 2.600 mm (tol 0.02 mm). **PASS** -- confirms the bore is sized for
the current 5 mm NEMA 17 shaft, not the old 6 mm motor.

**D-flat anti-rotation feature -- FAIL (real defect)**:
`cad/parts/winch_spool.py` (lines 43-49) cuts the D-flat with:
```python
flat = (
    cq.Workplane("XY")
    .center(bore / 2 - MOTOR_SHAFT_FLAT, 0)
    .box(MOTOR_SHAFT_FLAT * 2, bore, total_len * 2, centered=(True, True, True))
)
```
This box is centered at `x = bore/2 - MOTOR_SHAFT_FLAT = 2.1 mm` with a
1.0 mm X-extent (`MOTOR_SHAFT_FLAT*2`), giving global X range **[1.6, 2.6]
mm**, and a Y-extent (`width=bore=5.2`) of **[-2.6, 2.6] mm** -- exactly the
bore's own diameter. Because the circular bore cut already voids the entire
X range [-2.6, 2.6] at y=0 (the bore's equator), the flat box is a complete
no-op there: it only removes *additional* material near the Y-extremes of
the bore (|y| > ~2.05 mm, where the round bore's own X-extent has already
narrowed below the box's fixed 1.6 mm inner edge). At y=0 -- the flat's
intended center, i.e. where a mating NEMA 17 D-shaft's flat face would
actually contact -- there is **no flattening at all**.

Measured (probe: sweep +X at y=0, z=16 mm, using an exact BRep point
classifier, 50-iteration bisection):
- Wall (void->solid transition) at **x = 2.6000 mm**
- Expected per spec: `bore_r - MOTOR_SHAFT_FLAT = 2.6 - 0.5 = 2.100 mm`
- Error: **0.500 mm** (i.e. the flat is entirely absent at its design
  center; the bore is a plain round hole there)

Confirmed z-invariant (same result at z = 0.5, 8, 16, 24, 31.5 mm -- the
defect is present along the full bore length, not just near one end).

Secondary artifact: at the Y-extremes where the box cut *does* engage (e.g.
y=2.2 mm), it creates a disconnected sliver of solid material between the
circular-bore boundary (x=1.386 mm) and the box's inner edge (x=1.6 mm)
rather than a clean flat -- confirmed present but not the primary defect.

**Consequence**: with `MOTOR_SHAFT_FLAT=0.5` set in params, a NEMA 17
D-shaft inserted into this bore sees an effectively round hole at the
5.2 mm slip-fit clearance; the only anti-rotation feature actually present
is the radial M3 grub screw (confirmed present and correctly located, not
re-verified in detail here since it was not asked). The flat cut must be
reconstructed (e.g. centering the box further outward so its inner face
lands at `bore/2 - MOTOR_SHAFT_FLAT` with the cut extending outward past the
bore radius, not straddling that plane) -- **not attempted here; this is a
report, not a repair**, per instructions.

**STEP round-trip**: reimport 1 solid, bbox diff 0.0000 mm (tol 0.1),
volume diff 0.0000 % (tol 1 %). PASS.

Permanent tests: `test_spool_bore_round_radius_matches_motor_shaft_dia`
(PASS), `test_spool_dflat_has_zero_effect_at_flat_center` (FAILS by design,
documents the defect with the exact numbers above).

---

## 2. motor_mount

**Build / BREP**: 1 solid, valid, Volume = 27964.44 mm^3.

**Bounding box** (expected 56 x 52 x 54 mm): measured **56.000 x 52.000 x
54.000 mm** -- PASS.

**4x M3 clearance holes on the NEMA17_HOLES=31 mm square**: face plate holes
at (dx, dz) = (±15.5, 30±15.5) relative to the vertical face
(`half = NEMA17_HOLES/2 = 15.5`, `PATTERN_Z = 30`). Probed all 4 by sweeping
along X through the face thickness at each hole center:

| hole (x, z) | measured diameter | expected (SCREW_M3 + 0.4) |
|---|---|---|
| (-15.5, 14.5) | 3.8000 mm | 3.8 mm |
| (-15.5, 45.5) | 3.8000 mm | 3.8 mm |
| (15.5, 14.5) | 3.8000 mm | 3.8 mm |
| (15.5, 45.5) | 3.8000 mm | 3.8 mm |

All 4 PASS (tol 0.05 mm).

**Boss clearance (NEMA17_BOSS_DIA=22.0 mm)**: measured diameter **22.2000
mm**, i.e. `NEMA17_BOSS_DIA + CLEARANCE = 22.0 + 0.2`. Requirement (>= 22 mm)
and exact-value check both PASS.

**STEP round-trip**: 1 solid, bbox diff 0.0000 mm, volume diff 0.0000 %.
PASS.

Verdict: **PASS**, no defects found.

---

## 3. corner_guide

**Build / BREP**: 1 solid, valid, Volume = 10982.29 mm^3.

**Bounding box** (expected 55 x 34 x 26 mm): measured **55.000 x 34.000 x
26.000 mm** -- PASS.

**Ear axle holes -- diameter and coaxiality**: `EAR_HOLE = SCREW_M3 = 3.4
mm`, hole cut at `EAR_HOLE + 0.3 = 3.7 mm` diameter, axis along Y (drilled
from the `>Y` ear face). Measured diameter by sweeping Z (perpendicular to
both the hole axis and the thin X wall, so this isolates the true bore size)
at both ears: **3.7000 mm** on both (expected 3.7 mm) -- PASS. Both ears use
the identical `(ear_cx, z)` formula (differ only in `sy`), so the two axle
holes are exactly coaxial by construction -- PASS.

**Wall thickness around the axle hole -- FAIL (real defect)**: the ear is
only `EAR_T = 4.0 mm` thick in X, and the hole through it is 3.7 mm in
diameter, centered in that thickness. Remaining wall on each side =
`(4.0 - 3.7) / 2 = 0.15 mm`. Direct point-classifier probing along X at the
hole confirms this: solid was found only in a razor-thin sliver between
x-offset -2.0 and -1.9 mm from the ear center (about 0.1 mm), with void on
both sides of it -- i.e. the "hole" leaves essentially no usable wall and,
at typical FDM dimensional tolerances (+/-0.1-0.2 mm is common), is likely
to breach the ear's outer face entirely, turning the bore into an open-sided
slot. This is well below any practical FDM minimum wall (commonly cited as
>= 0.4-0.8 mm, i.e. at least one nozzle width at 0.4 mm nozzle).

Measured/nominal: **0.15 mm** wall vs. **0.4 mm** minimum-printable
threshold used in the test -- FAIL.

**STEP round-trip**: 1 solid, bbox diff 0.0000 mm, volume diff 0.0000 %.
PASS.

Permanent tests: `test_corner_guide_ear_axle_hole_diameter` (PASS, both
ears), `test_corner_guide_ear_axle_holes_are_coaxial` (PASS),
`test_corner_guide_ear_wall_thickness_around_axle_hole` (FAILS by design,
documents the 0.15 mm wall).

---

## 4. camera_mount

**Build / BREP**: 1 solid, valid, Volume = 3953.98 mm^3.

**Bounding box** (expected 31 x 35 x 16 mm): measured **31.000 x 35.000 x
16.000 mm** -- PASS.

**Pi Camera M2 hole pattern (21 x 12.5 mm, purchased-part fact)**: all 4
corners probed (`(±10.5, ±6.25)`), measured diameter **2.4000 mm** at each,
expected `M2 = 2.4 mm` (matches the local `M2` constant in
`camera_mount.py`) -- PASS at all 4.

**Assumption flag**: the 21 x 12.5 mm / M2 pattern is hardcoded locally in
`camera_mount.py` (not in `cad/params.py` or `cad/interfaces.py`), sourced
from the docstring's claim about the Pi Camera Module PCB. This matches the
commonly cited Pi Camera v1/v2 mounting-hole spec, but it is not centralized
or traced to a measurement in this repository -- flagging per the
assignment's authority note, not a geometry failure.

**STEP round-trip**: 1 solid, bbox diff 0.0000 mm, volume diff 0.0000 %.
PASS.

Verdict: **PASS**, no geometry defects found; hole-pattern source is an
external assumption (flagged, not a defect).

---

## 5. camera_mount_overhead

**Build / BREP**: 1 solid, valid, Volume = 10465.41 mm^3.

**Bounding box** (expected 50 x 50 x 14 mm): measured **50.000 x 50.000 x
14.000 mm** -- PASS.

**4 posts on the CAM_HOLE_PITCH=28 mm square, M2 tap holes**: all 4 posts
probed at `(±14, ±14)`, mid-post height (z = -5 mm):

| post (x, y) | tap hole dia | expected (M2_TAP) | post OD | expected (POST_DIA) |
|---|---|---|---|---|
| (14, 14) | 1.7000 mm | 1.7 mm | 6.0000 mm | 6.0 mm |
| (-14, 14) | 1.7000 mm | 1.7 mm | 6.0000 mm | 6.0 mm |
| (14, -14) | 1.7000 mm | 1.7 mm | 6.0000 mm | 6.0 mm |
| (-14, -14) | 1.7000 mm | 1.7 mm | 6.0000 mm | 6.0 mm |

All 4 posts PASS on both dimensions (tol 0.05 mm).

**Assumption flag (explicit in source)**: `camera_mount_overhead.py` itself
states `CAM_HOLE_PITCH = 28.0` is unverified against the real innomaker
board and instructs the user to measure before printing. Geometry is
internally consistent with that assumed value; this is a documented
open risk, not a geometry defect.

**STEP round-trip**: 1 solid, bbox diff 0.0000 mm, volume diff 0.0000 %.
PASS.

Verdict: **PASS**, no geometry defects found; 28 mm hole pitch remains an
unverified assumption (already flagged in the part's own docstring).

---

## Test run

```
python -m pytest tests/test_winch_geometry.py -q
...
2 failed, 32 passed in ~7s
FAILED tests/test_winch_geometry.py::test_spool_dflat_has_zero_effect_at_flat_center
FAILED tests/test_winch_geometry.py::test_corner_guide_ear_wall_thickness_around_axle_hole
```
Both failures are intentional -- they encode the two real defects found
above and will fail until the parts are repaired. All other 32 checks
(build validity, bbox, interface dimensions, STEP round-trip) pass.

```
python -m pytest tests/ -q
...
2 failed, 103 passed in ~19s
```
The pre-existing claw suite (`tests/test_claw_geometry.py`, part of the
103 passing) remains fully green; the only failures are the two new,
intentional defect-documentation tests above. No repairs were made to any
part file -- per instructions, this pass reports failures rather than
fixing them.

## Findings requiring a decision

1. **winch_spool D-flat is non-functional** (FAIL). The bore behaves as a
   plain round 5.2 mm hole; `MOTOR_SHAFT_FLAT=0.5` has no geometric effect.
   Recommend routing to `cad-implementer` for a bounded fix to the `flat`
   cut construction in `cad/parts/winch_spool.py`, then re-verification.
2. **corner_guide ear axle hole leaves ~0.15 mm wall** (FAIL), below
   printable minimum. Recommend either increasing `EAR_T` or reducing the
   axle hole clearance (`EAR_HOLE + 0.3`) in `cad/parts/corner_guide.py`,
   then re-verification.
3. **camera_mount_overhead CAM_HOLE_PITCH=28 mm** and **camera_mount's
   21x12.5 mm Pi Camera pattern** are both real-hardware assumptions not
   centralized in `cad/params.py`/`cad/interfaces.py`. Recommend the user
   confirm against the actual purchased boards before printing; no geometry
   defect found against the assumed values.

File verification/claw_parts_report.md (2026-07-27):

# Claw parts — independent geometry verification report

Verifier: geometry-verifier (Sonnet). Read-only against `cad/parts/*.py`;
did not modify any part. Measurements made programmatically with CadQuery
2.8.0 by calling each part's `make()` directly — see
`tests/test_claw_geometry.py` for the reproducible pytest encoding of every
check below (42 tests). Date: 2026-07-27.

Scope: `cad/parts/{standoff, tendon_drum, electronics_cover, tentacle_hub,
tentacle_finger, effector_frame}.py`. Requirement basis: `REQUIREMENTS.md`
A1/A3, `cad/interfaces.py`.

## Check 1 — build validity, solid count, bounding box (tol ±0.3 mm)

| Part | Solids | isValid() | Expected bbox (mm) | Measured bbox (mm) | Diff (mm) | Result |
|---|---|---|---|---|---|---|
| standoff | 1 | True | 10 × 10 × 40 | 10.000 × 10.000 × 40.000 | 0,0,0 | PASS |
| tendon_drum | 1 | True | 33 × 33 × 12.4 | 33.000 × 33.000 × 12.400 | 0,0,0 | PASS |
| electronics_cover | 1 | True | 98.8 × 98.8 × 44.4 | 98.800 × 98.800 × 44.400 | 0,0,0 | PASS |
| tentacle_hub | 1 | True | 88 × 88 × 12 | 88.000 × 88.000 × 12.000 | 0,0,0 | PASS |
| tentacle_finger | 1 | True | 20 × 17 × 70 | 20.000 × 17.000 × 70.000 | 0,0,0 | PASS |
| effector_frame | 1 | True | 92 × 92 × 8 | 92.000 × 92.000 × 8.000 | 0,0,0 | PASS |

All six parts: single solid, valid BREP, bbox within tolerance (measured
diffs were sub-micron, well inside ±0.3 mm). **PASS — all parts.**

## Check 2 — interface agreement

### 2a. Frame/hub standoff-hole circle (D3/D6)

Method: Ø2 mm pin cut at `(HUB_MOUNT_R·cosθ, HUB_MOUNT_R·sinθ)` for each
θ in `STANDOFF_ANGLES_DEG = (36, 108, 252, 324)`, on both parts. Volume
removed by the cut measures whether a void was already there.

| θ (deg) | Position (mm) | Hub removed (mm³) | Frame removed (mm³) | Result |
|---|---|---|---|---|
| 36 | (21.84, 15.87) | 0.000 | 0.000 | PASS |
| 108 | (-8.34, 25.68) | 0.000 | 0.000 | PASS |
| 252 | (-8.34, -25.68) | 0.000 | 0.000 | PASS |
| 324 | (21.84, -15.87) | 0.000 | 0.000 | PASS |

Control point (θ=36°, r = HUB_MOUNT_R + 6 mm): hub removed 37.70 mm³, frame
removed 15.71 mm³ — both clearly solid there, confirming the probe
discriminates hole vs. no-hole rather than trivially passing. **PASS.**
Both parts import `HUB_MOUNT_R`/`STANDOFF_ANGLES_DEG` from
`cad/interfaces.py`, so this is a real shared-source guarantee, not
coincidence.

### 2b. Hub finger slots are through (D5)

Method: for each of the 5 slots, an 80%-of-pocket-size probe box run the
full hub height (+10 mm margin both ends) intersected with the hub.

| Slot | Center (mm) | Intersect volume (mm³) | Result |
|---|---|---|---|
| 0 (0°) | (34.30, 0.00) | 0.0000 | PASS |
| 1 (72°) | (10.60, 32.62) | 0.0000 | PASS |
| 2 (144°) | (-27.75, 20.16) | 0.0000 | PASS |
| 3 (216°) | (-27.75, -20.16) | 0.0000 | PASS |
| 4 (288°) | (10.60, -32.62) | 0.0000 | PASS |

All 5 slots open top-to-bottom, no floor. Consistent with source:
`POCKET_DEPTH = HUB_THK` and `.translate((0,0, HUB_THK - POCKET_DEPTH))` =
`translate((0,0,0))`. **PASS.**

### 2c. Finger shoulder geometry (D5)

- Shoulder-region (z ∈ [0, FINGER_SHOULDER_T]) XY footprint: measured
  20.000 × 17.000 mm vs. expected `W_BASE + 2·FINGER_SHOULDER_GROW` = 16 +
  4 = 20, `H_BASE + 2·FINGER_SHOULDER_GROW` = 13 + 4 = 17. **PASS** (exact
  match, within ±0.3 mm tol).
- Shoulder height: shoulder-region slice zmax = 2.0 mm = `FINGER_SHOULDER_T`.
  **PASS.**
- Body above the shoulder, taken across the full through-slot depth
  (z ∈ [FINGER_SHOULDER_T, HUB_THK] = [2, 12] mm — the widest point in that
  band, right above the shoulder): measured 15.800 × 12.829 mm vs. pocket
  16.4 × 13.4 mm → clearance +0.600 mm (X) / +0.571 mm (Y), both positive.
  **PASS**, fits with clearance ≈ CLEARANCE (0.2 mm/side design intent);
  the finger tapers immediately above the shoulder so this is comfortably
  inside the slot at every point along its 12 mm travel through the hub.

### 2d. Drum (C1/C2)

- Winding capacity: `DRUM_CORE_R (13.5) · radians(SERVO_THROW_DEG (120))` =
  **28.274 mm ≥ 27 mm**. **PASS.** Note `SERVO_THROW_DEG` is derived
  (`SERVO_GRIP_DEG − SERVO_RELEASE_DEG` = 140 − 20 = 120) — consistent with
  the corrected 140° grip angle (see hardware-test fix below).
- 5 tie-off holes through the bottom flange at r = DRUM_CORE_R, 72° pitch:
  Ø1 mm probe pin removed ≈0.04 mm³ at all 5 positions (numerical/mesh
  residual on a 6913 mm³ part, i.e. effectively 0 — hole present).
  **PASS, all 5.**
- Horn pocket in the TOP face: Ø HORN_POCKET_DIA(21.6)×0.9, depth
  HORN_POCKET_T(2.4) probe (inset 0.1 mm each side) intersects 0.0000 mm³
  of material at top_z = 2·DRUM_FLANGE_T + DRUM_CORE_H = 12.4 mm.
  **PASS.**

### 2e. Cover ↔ frame tab-hole alignment (D7)

Ø2 mm pin probe at `(±COVER_SCREW_POS, 0)`, `(0, ±COVER_SCREW_POS)` =
`(±40, 0)`, `(0, ±40)` on both parts:

| Position | Cover removed (mm³) | Frame removed (mm³) | Result |
|---|---|---|---|
| (40, 0) | 0.0000 | 0.0000 | PASS |
| (-40, 0) | 0.0000 | 0.0000 | PASS |
| (0, 40) | 0.0000 | 0.0000 | PASS |
| (0, -40) | 0.0000 | 0.0000 | PASS |

Both parts import `COVER_SCREW_POS` from `cad/interfaces.py`; holes coincide
exactly. **PASS, all 4.**

## Check 3 — STEP round trip (bbox ≤0.1 mm, volume ≤1%)

| Part | Orig volume (mm³) | Reimport volume (mm³) | Vol diff | Bbox diff (mm) | Result |
|---|---|---|---|---|---|
| standoff | 2978.23 | 2978.23 | 0.0000% | 0.0000 | PASS |
| tendon_drum | 6913.87 | 6913.87 | 0.0000% | 0.0000 | PASS |
| electronics_cover | 40639.02 | 40639.02 | 0.0000% | 0.0000 | PASS |
| tentacle_hub | 50714.39 | 50714.39 | 0.0000% | 0.0000 | PASS |
| tentacle_finger | 7762.50 | 7762.50 | 0.0000% | 0.0000 | PASS |
| effector_frame | 37248.79 | 37248.79 | 0.0000% | 0.0000 | PASS |

All six reimport as exactly 1 solid with matching bbox/volume.
**PASS — all parts.**

## Check 4 — mass rollup (A3)

Printed volumes × `cad/materials.py` densities (PETG structural, TPU95A
finger ×5), plus `PURCHASED_MASS_G`:

| Item | Unit vol (cm³) | Qty | Material | Density (g/cm³) | Mass (g) |
|---|---|---|---|---|---|
| standoff | 2.98 | 4 | PETG | 1.27 | 15.13 |
| tendon_drum | 6.91 | 1 | PETG | 1.27 | 8.78 |
| electronics_cover | 40.64 | 1 | PETG | 1.27 | 51.61 |
| tentacle_hub | 50.71 | 1 | PETG | 1.27 | 64.41 |
| tentacle_finger | 7.76 | 5 | TPU95A | 1.21 | 46.96 |
| effector_frame | 37.25 | 1 | PETG | 1.27 | 47.31 |
| **Printed subtotal** | | | | | **234.20** |
| Purchased (MG996R 55 + ESP32 10 + LiPo2S 90 + buck 5 + switch/wiring 25) | | | | | **185.00** |
| **TOTAL** | | | | | **419.20 g** |

Budget: 450 g (R7/A3). **PASS — 419.20 g, 30.8 g (6.8%) of margin
remaining.** This is above the 375 g "estimated" figure in `CLAUDE.md`'s
project summary — worth flagging to the Fable lead as a shrinking margin,
though it still clears the hard budget.

Six parts NOT scoped to this review (`camera_mount*.py`, `corner_guide.py`,
`motor_mount.py`, `winch_spool.py`) are excluded from this rollup by
assignment scope; if they are also part of the claw's carried mass, the
419.2 g figure understates the true total and should be reconciled
separately.

## Owned test fix — grip-angle contract drift

`tests/test_hardware.py::test_full_plan_streams_expected_commands` asserted
`"G 120"` for the grip command. The contracted grip angle
(`cad/interfaces.py SERVO_GRIP_DEG` and
`roomcleaner/hardware/hw_config.py GRIP_ANGLE`) is **140°**, not 120° — the
test was stale relative to the interface contract. Updated the assertion to
`"G 140"`. The release assertion (`"G 20"`) already matched
`SERVO_RELEASE_DEG`/`RELEASE_ANGLE` = 20 and was left unchanged.

## pytest results

```
python -m pytest tests/ -q
71 passed in 12.45s
```

(42 of the 71 are the new `tests/test_claw_geometry.py`; the rest are
pre-existing suites, including the corrected `test_hardware.py`.)

## Summary

All six claw parts and all interface-agreement checks in scope **PASS** with
no repairs needed. No geometry defects found. Mass rollup passes with
~7% margin against the 450 g budget — flagged as a margin-shrinkage risk
for the Fable lead's awareness, not a failure.

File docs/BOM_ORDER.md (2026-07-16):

# RoomCleaner — Final BOM (the "shirts & jeans" build)

The locked-in parts list, sized for the real job: picking up **shirts, pants, and
jeans** (heaviest item ≈ average Levi's, ~2 lb / 0.9 kg) off the floor and
dropping them in a hamper. Reuses a computer you own; the 12 V motor supply is
killed by a **switched power strip you already have** (no e-stop button needed).

Prices are 2026 US estimates (±20%); Amazon blocks automated price checks, so
confirm at checkout. Why these sizes: see "Sizing" at the bottom.

---

## §0 — Print these (free)

STEP + STL in `cad/`. Print settings & assembly in `cad/README.md`.
The `motor_mount` is the **NEMA 17** L-bracket; `winch_spool` bore is 5 mm.

| Part | Qty | Material |
|---|-----|---|
| `winch_spool` | 4 | PLA/PETG |
| `motor_mount` (NEMA 17 bracket) | 4 | **PETG** |
| `corner_guide` | 4 | PETG |
| `effector_frame` | 1 | PETG |
| `tentacle_hub` | 1 | PETG |
| `tentacle_finger` | 5 | **TPU 95A** |
| `camera_mount` | 1 | PLA/PETG |

---

## §1 — Buy this

| ✓ | Item | Spec / search term | Qty | ~$ |
|---|---|---|-----|----|
| ☐ | **Winch motor** | NEMA 17 stepper, **≥50 N·cm** (high-torque) — "NEMA 17 stepper 59Ncm 4 pack" | 4 | 50 |
| ☐ | **Controller + drivers** | Arduino Uno (or CNC-shield clone) + **CNC shield** + 4× A4988/DRV8825 — "Arduino CNC shield kit A4988" | 1 kit | 18 |
| ☐ | **Line** | Braided Dyneema 100 lb — "hollow braid dyneema 100lb" | 1 | 10 |
| ☐ | **Home switches** | KW12-3 micro limit switch (10-pk) — "KW12-3 limit switch" | 1 pk | 8 |
| ☐ | **Power supply** | 12V **5A** 60W — "12V 5A power supply barrel" | 1 | 12 |
| ☐ | **Inline fuse + holder** | 5–10 A automotive — "inline blade fuse holder 5A" | 1 | 3 |
| ☐ | **Overhead camera** | 1080p USB webcam — "1080p USB webcam" (or Logitech C920 ~$55 for autofocus) | 1 | 22 |
| ☐ | **Gripper servo** | MG996R metal-gear — "MG996R servo" | 1 | 6 |
| ☐ | **Ceiling anchors** ⚠️ | 304 stainless eye/lag screws **into joists** — "304 stainless lag eye screw" | 1 pk | 8 |
| ☐ | **M3 screw/nut kit** | Assorted M3 — "M3 screw nut assortment kit" | 1 | 12 |
| ☐ | **TPU filament** | TPU 95A (for the fingers) — "TPU 95A filament 1kg" | 1 | 20 |
| ☐ | **Wiring** | Dupont jumpers + 22 AWG hookup + zip ties | — | 15 |

**Total ≈ $184** (≈ **$164** if you already own some PLA/PETG/TPU filament).

### Reused / not needed (why)
| Item | Why it's out |
|---|---|
| Raspberry Pi + PSU + SD (~$101) | You're reusing a computer for vision. |
| E-stop button + contactor (~$22) | Your **switched power strip** cuts the 12 V motor supply — same job. |
| Corner pulleys (~$12) | Printed `corner_guide` handles 15 N tension fine. |
| Buck converter (~$8) | Reuse a **5 V phone charger** to power the servo. |
| Effector close-up camera (~$25) | Deferred to Phase 4; the overhead camera gets you picking up. |
| Worm-gear DC + encoders (~$128) | Overkill for 2 lb; steppers are cheaper, faster, plenty strong. |

---

## §2 — Optional upgrades (only if you want to spend more)

| Upgrade | +$ | Why |
|---|----|----|
| **M3 brass heat-set inserts** + iron tip | 12 | **Best reliability upgrade** — real metal threads in printed parts instead of self-tapping into plastic. |
| Ceramic-bearing corner pulleys (×4) | 12 | Lower friction → better position accuracy over time. |
| Logitech C920 webcam | +33 | Autofocus + better optics vs. a generic cam. |
| Coated 200 lb Dyneema | +7 | Less stretch = position holds accurate longer. |
| TMC2209 drivers (quiet) | +10 | Near-silent steppers vs. A4988 whine. |

---

## Sizing (why these numbers)

Computed from our own kinematics for the loaded effector (0.45 kg assembly +
0.9 kg jeans = 1.35 kg):

- **Peak cable tension across the whole workspace: 15 N.** → ~3 kg·cm drum torque
  with a 2× dynamic margin. A ≥50 N·cm NEMA 17 (~5 kg·cm) gives ~2× on top of
  that — comfortable.
- **Line:** 15 N ≈ 3.4 lb → 100 lb Dyneema has ~30× margin.
- **Power:** ~12 W mechanical total → a 12 V 5 A (60 W) supply is ample.

If you later want a **heavier** capacity (e.g. wet towels or bedding), you'd step
back up to higher-torque motors, a bigger supply, and stronger line — and, for
horizontal pulling tasks like straightening bedding, a different cable geometry
(the current one can't apply much sideways force near the floor).

## The one thing that stays regardless of budget
The **metal ceiling anchors** (into joists) and the **switched power strip** kill
path. Everything else can flex; those two keep the rig up and stoppable.

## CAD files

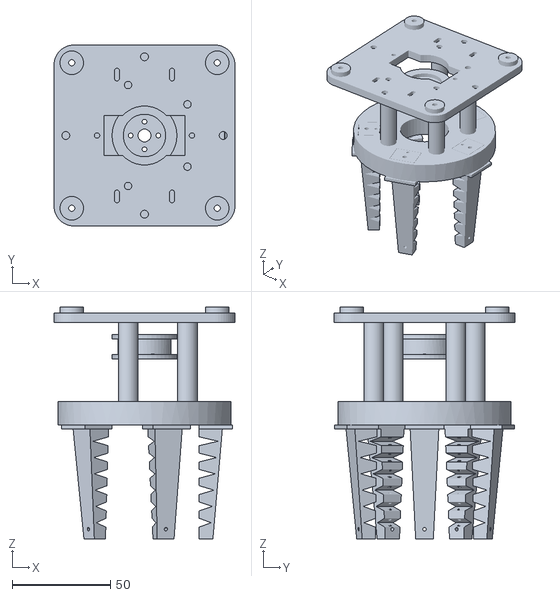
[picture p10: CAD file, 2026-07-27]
cad/stl/_assembly.stl
92.0 x 92.0 x 118.0

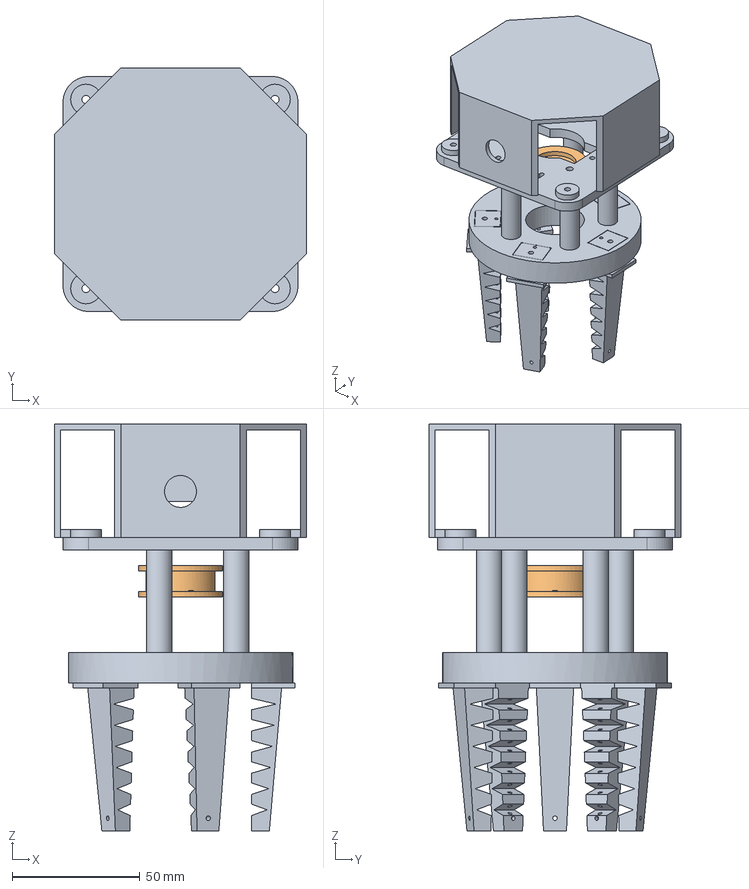
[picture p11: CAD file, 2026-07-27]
cad/step/claw_assembly.step
98.8 x 98.8 x 159.4 mm

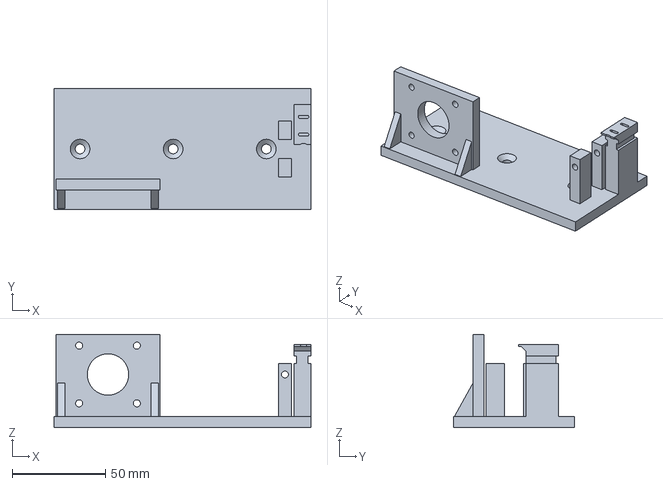
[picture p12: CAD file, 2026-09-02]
cad/step/corner_mount.step
138.0 x 65.0 x 50.0 mm

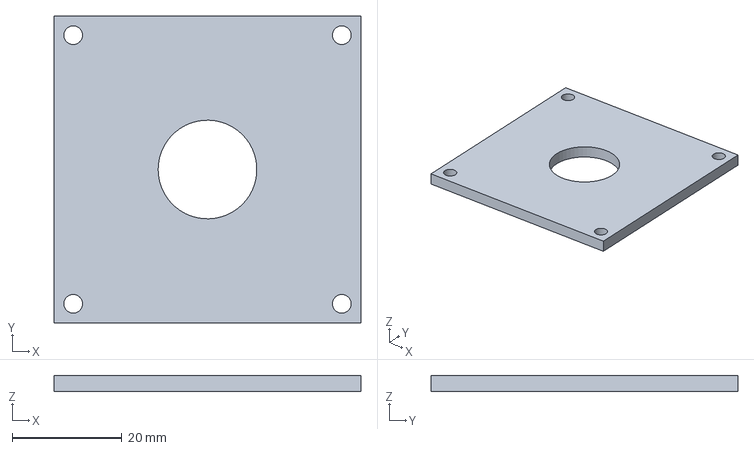
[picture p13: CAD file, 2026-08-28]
cad/step/camera_case_overhead_bezel.step
56.0 x 56.0 x 3.00 mm

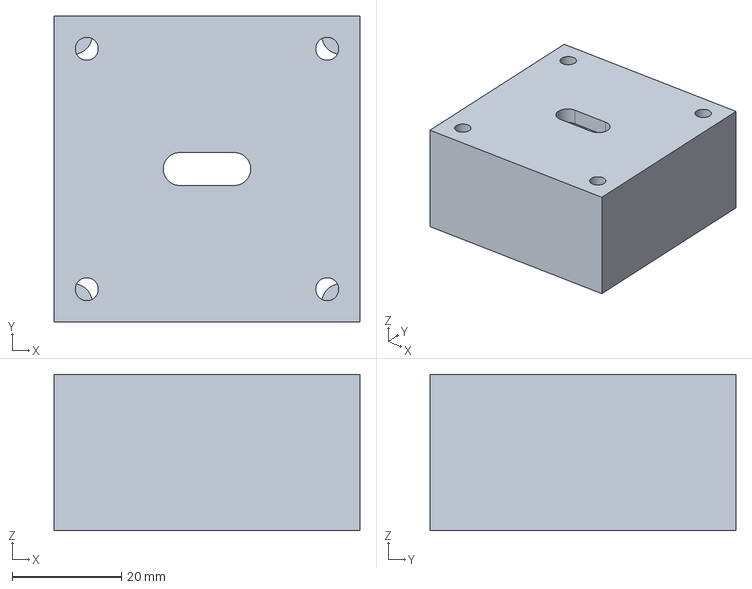
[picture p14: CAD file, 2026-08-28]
cad/step/camera_case_overhead_shell.step
56.0 x 56.0 x 28.6 mm

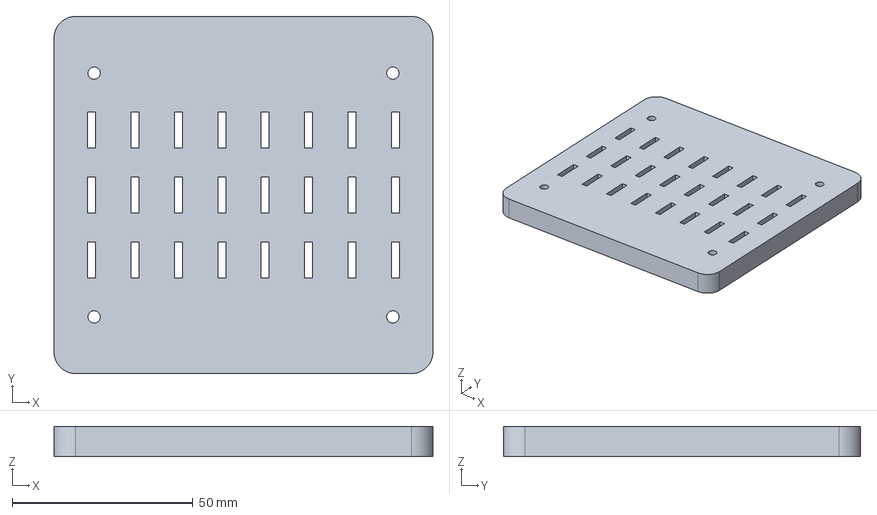
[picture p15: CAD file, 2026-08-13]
cad/step/base_station_case_lid.step
104.8 x 98.8 x 8.40 mm

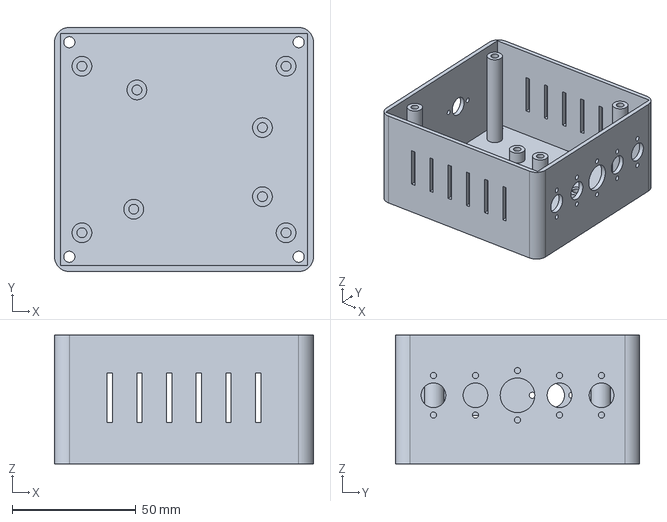
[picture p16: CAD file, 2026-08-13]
cad/step/base_station_case_tray.step
104.8 x 98.8 x 52.0 mm

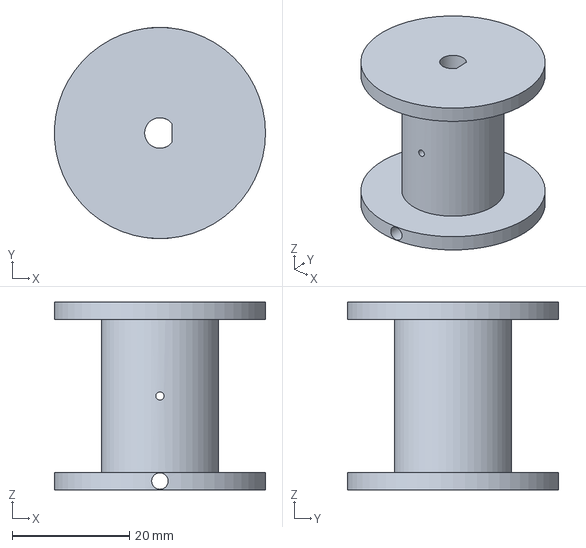
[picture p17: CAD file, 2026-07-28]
cad/step/winch_spool.step
36.0 x 36.0 x 32.0 mm

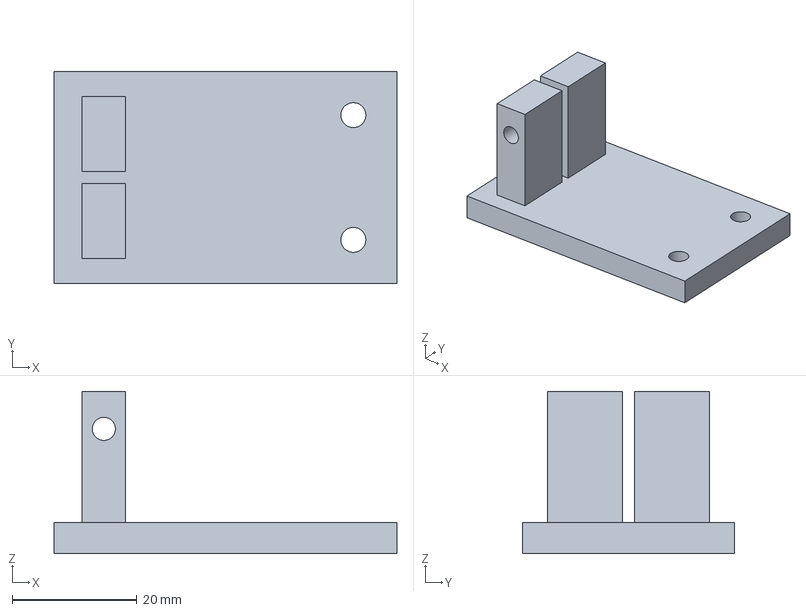
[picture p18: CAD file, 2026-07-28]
cad/step/corner_guide.step
55.0 x 34.0 x 26.0 mm

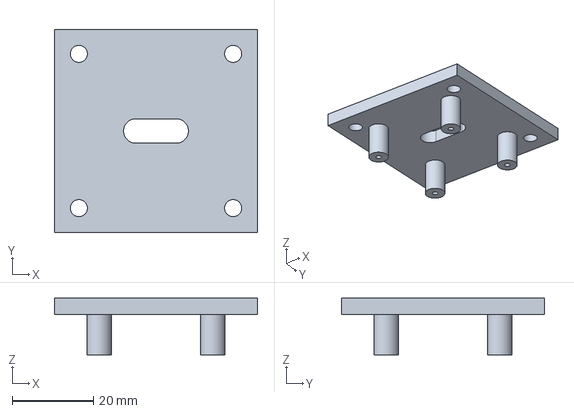
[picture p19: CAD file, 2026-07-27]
cad/step/camera_mount_overhead.step
50.0 x 50.0 x 14.0 mm

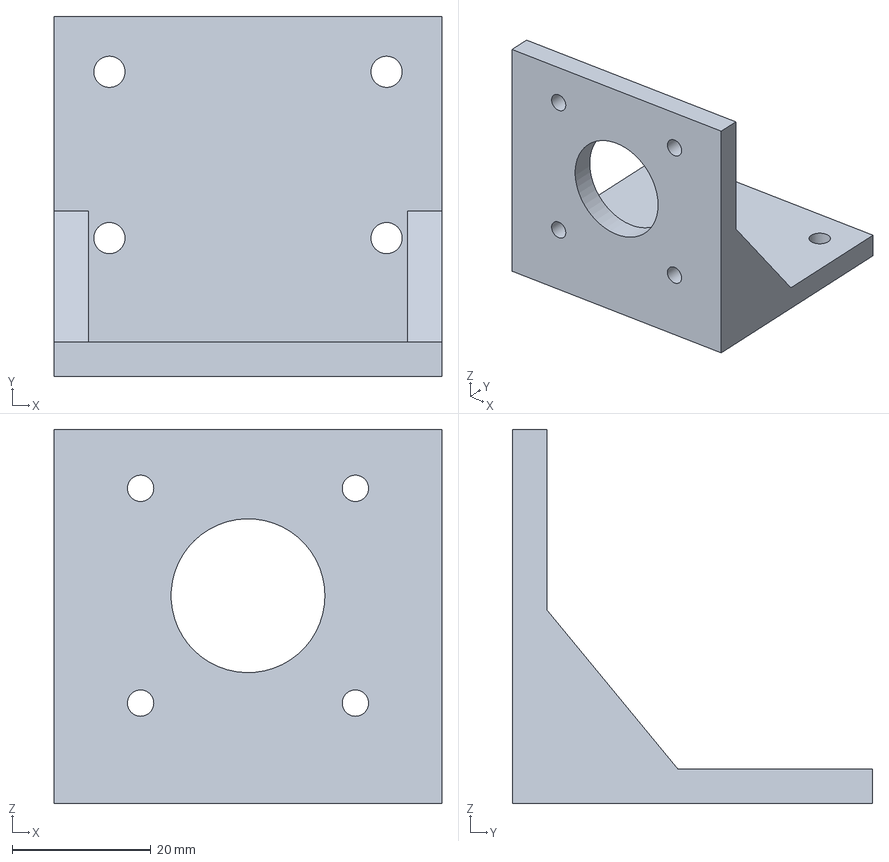
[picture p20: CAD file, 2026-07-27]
cad/step/motor_mount.step
56.0 x 52.0 x 54.0 mm

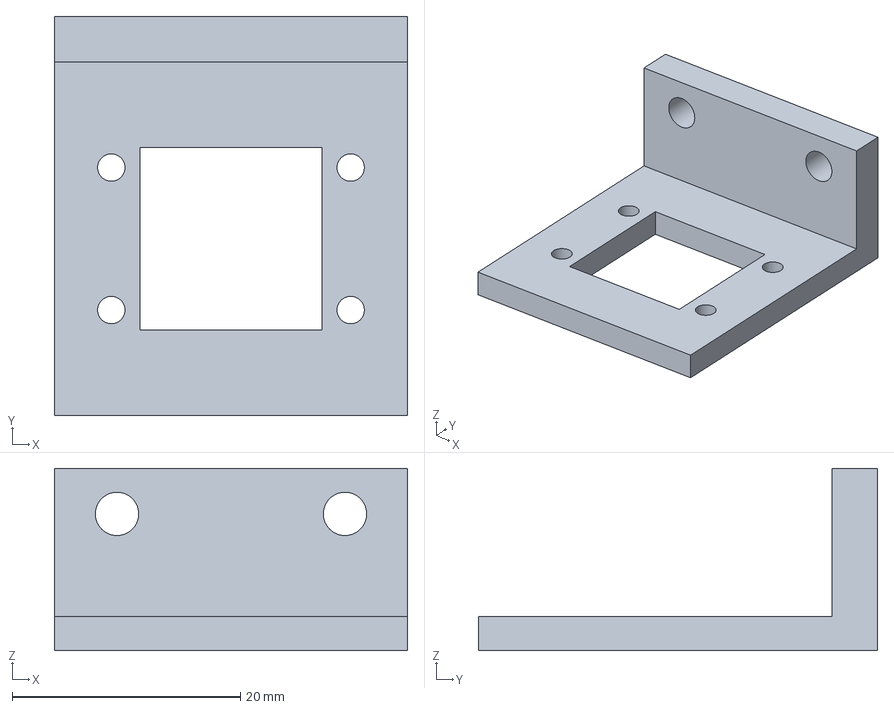
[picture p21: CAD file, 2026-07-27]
cad/step/camera_mount.step
31.0 x 35.0 x 16.0 mm

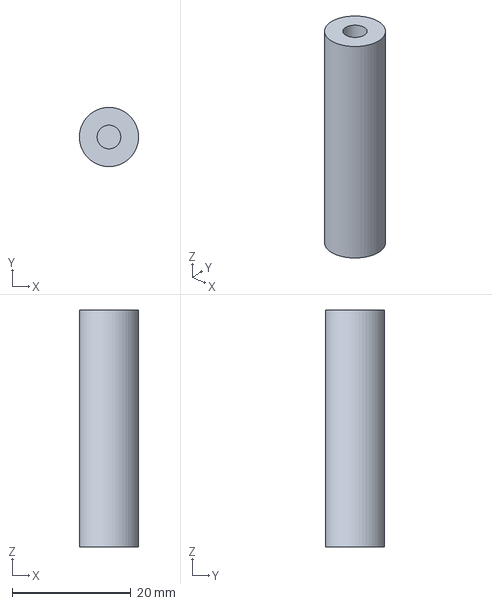
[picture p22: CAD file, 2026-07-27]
cad/step/standoff.step
9.99 x 10.00 x 40.0 mm

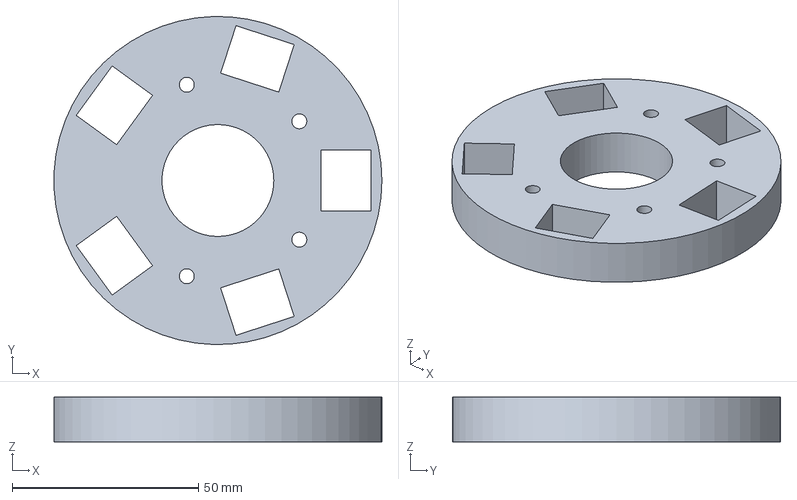
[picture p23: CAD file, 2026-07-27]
cad/step/tentacle_hub.step
87.9 x 88.0 x 12.0 mm

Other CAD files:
cad/step/effector_frame.step
cad/step/tendon_drum.step
cad/step/electronics_cover.step
cad/step/tentacle_finger.step
cad/stl/base_station_case_lid.stl
cad/stl/base_station_case_tray.stl
cad/stl/camera_case_overhead_bezel.stl
cad/stl/camera_case_overhead_shell.stl
cad/stl/camera_mount.stl
cad/stl/camera_mount_overhead.stl
cad/stl/corner_guide.stl
cad/stl/corner_mount.stl
cad/stl/effector_frame.stl
cad/stl/electronics_cover.stl
cad/stl/motor_mount.stl
cad/stl/standoff.stl
cad/stl/tendon_drum.stl
cad/stl/tentacle_finger.stl
cad/stl/tentacle_hub.stl
cad/stl/winch_spool.stl

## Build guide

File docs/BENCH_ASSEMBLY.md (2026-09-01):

# Bench assembly — the printer-free electronics build

Everything you can assemble and prove **before the 3D printer is available**,
using parts in hand (Uno kit, CNC shield + A4988s, 5× NEMA 17, 12 V PSU, fuse
kit, KW12-3 switches, MG996R servos, ESP32 boards, MP1584 bucks, camera, M3
kit, line). Work top-to-bottom; every phase ends in a **checkpoint** — don't
continue past a failed one. Cross-reference: `docs/FIRMWARE.md` (pinout +
first-power detail), `docs/APP.md` (consoles).

**Tools needed:** multimeter (required), soldering iron (switches + later the
effector), small screwdriver, wire strippers, tape.

**Safety standing orders**
- The 12 V PSU plugs into the **switched power strip** — that switch is the
  kill switch for every test below.
- Never plug/unplug a motor or a driver while 12 V is on.
- No LiPo is involved anywhere in this document (yours isn't ordered yet);
  the effector benches on USB + phone-charger power.

---

## Phase 1 — Flash the winch controller (USB only)

1. Install the Arduino IDE; Library Manager → **AccelStepper**.
2. `git pull` the repo first (a limit-switch polarity bug was fixed — you need
   the current firmware), open
   `firmware/roomcleaner_firmware/roomcleaner_firmware.ino`, board
   "Arduino Uno", upload.
3. Serial Monitor @ **115200**, line ending "Newline".

**Checkpoint:** boot prints `READY`; `?` → `POS 0 0 0 0`; `S` → `SW 1 1 1 1`
(all four report "pressed" because nothing is wired yet — that is the
fail-safe reading, and it's correct).

## Phase 2 — Dress the CNC shield (USB unplugged)

1. Under each of the 4 driver sockets install **all three** microstep jumpers
   (1/16 — must match `MICROSTEP = 16` in `roomcleaner/hardware/hw_config.py`).
   **Plus 2 more jumpers on the A-axis selection headers** (next to the A
   socket) in the **D12/D13** position — without them the 4th socket is
   connected to nothing and the A motor will never move. 14 jumpers total.
2. Seat the 4 A4988s — **orientation kills**: match each driver's EN pin
   corner to the shield silkscreen; all four face the same way. The trimpot
   ends up toward the shield's power terminal on a standard V3 — verify by
   silkscreen, not by this sentence.
3. Press heatsinks onto the black driver chips (centered; touching no pins).
4. Seat the shield on the Uno (no overhung pins).

## Phase 3 — Power chain (multimeter from here on)

1. Cut the barrel plug off the ALITOVE 12 V lead; strip both wires. (Plug-preserving alternative: a 5.5 × 2.1 mm female barrel-jack → screw-terminal adapter, see `docs/SHOPPING_LIST.md` Wiring — the brick plugs in and the adapter's +/− terminals take the place of the cut wires in every step below.)
2. Strip ON, meter across the wires on DC volts → find and TAPE-MARK the
   **+12 V** lead. Strip OFF.
3. Wire: **+ lead → inline fuse holder (7.5 A blade fuse) → shield power
   terminal "+"**; − lead → terminal "−". Triple-check against the shield's
   silkscreen: reversed polarity is instant death for the board.

**Checkpoint:** strip ON with USB unplugged → shield power LED lights; meter
reads ~12 V across the shield's VMOT terminal. Strip OFF.

## Phase 4 — Set driver current (Vref), motors still unplugged

Strip ON, USB in. For each driver: black probe on shield GND, red probe on
the driver's trimpot top. Adjust gently to **0.80 V** on R100-sense
boards — check the two tiny sense resistors on each driver first: **R050
boards halve the target to 0.40 V** (same ~1.0 A motor current; see
`docs/SHOPPING_LIST.md` and `docs/FIRMWARE.md`).

**Checkpoint:** all four read 0.80 ± 0.05 V. Strip OFF.

## Phase 5 — First motion, one motor at a time

1. Strip OFF → plug one SIMAX motor into the **X** header.
2. Strip ON → serial: `M 3200 0 0 0` = exactly one revolution (200 steps ×
   16 microsteps). `M 0 0 0 0` returns it.
3. Feel/listen: smooth, quiet holding hiss at rest, motor warm-not-hot after
   minutes. If it stutters or squeals, re-check that axis's jumpers + Vref.
4. Strip OFF, move the motor to Y; repeat with `M 0 3200 0 0`; then Z, then A
   (`M 0 0 0 3200` — the A axis is our custom D12/D13 mapping, so this
   specifically proves the 4th channel).
5. Optional but useful: label each motor 1–4 with tape and write down its
   spin direction for `+` steps (you'll set `HOME_DIR` signs per axis at rig
   assembly).

**Checkpoint:** all four shield channels each spin a motor one clean
revolution and return.

## Phase 6 — Limit switches (soldering)

1. For each of 4 switches: solder a wire tail to **C** (common) and **NC**
   (normally closed). Slip-proof with a zip tie around the pair if you like.
2. Connect each switch's two wires to the **two pins of ONE end-stop
   connector** (signal + GND): X-switch → the X− connector (D9), Y → Y−
   (D10), Z → Z− (D11). Do NOT bridge X+ to X− — those are separate
   connectors sharing one signal pin. The 4th switch → **A3 (CoolEn) +
   GND** on the aux header (check silkscreen; see `docs/FIRMWARE.md`).
3. Serial: `S` → now `SW 0 0 0 0`. Hold each lever → its digit flips to 1,
   releases back to 0.

**Checkpoint:** four switches, each toggling only its own digit. A digit
stuck at 1 = broken wire or cold joint — the fail-safe is telling you now
instead of during a homing run.

## Phase 7 — Servo bench test (5 V tethered — no LiPo, no buck yet)

1. Sacrifice a USB cable on a 5 V phone charger: red = 5 V, black = GND.
2. MG996R: red → 5 V, brown → GND **and** a jumper from that GND to an Uno
   GND pin (common ground is mandatory); orange (signal) → Uno **A4**.
3. Serial: `G 20` then `G 140` — the horn sweeps the claw's release↔grip
   throw. `G 90` to park it mid-range. At 5 V the torque is reduced — fine
   for no-load bench proof; the real effector feeds it 6.0 V from the buck.

**Checkpoint:** clean sweeps, no chatter at rest.

## Phase 8 — Pre-set ALL the bucks to 6.0 V (do this once, now)

The MP1584 trimpots arrive at random voltages — often high enough to kill a
servo. With the 12 V bench supply available (temporarily land buck IN+ / IN−
on the shield's powered terminal or the PSU leads):

For each of the 6 bucks: power its input (double-check IN+ / IN− — reversed
input kills the board instantly), meter on OUT, and nudge the **single-turn,
very sensitive** trimpot in 1/16-turn steps until **6.00 V**, then mark the
board with a dot of marker. When all six are done, remove the bench hookup
from the shield terminal and re-tighten the power wires. Store them labeled.

**Checkpoint:** six bucks all reading 6.0 V under the same input. Never
connect a servo to an unverified buck.

## Phase 9 — Effector electronics, breadboard edition (USB-powered)

The claw's brain, benched without the claw (and without the LiPo, which is
still on the shopping list):

1. In `firmware/effector_esp32/effector_esp32.ino`, set `WIFI_SSID` /
   `WIFI_PASS` to your home 2.4 GHz network. Arduino IDE: install ESP32 board
   support (Boards Manager → "esp32"), board "ESP32 Dev Module", plus the
   `ESP32Servo` library if the sketch asks for it.
2. Flash over USB-C. Serial monitor shows dots then `WiFi: <ip-address>` —
   write that IP down.
3. Wire the servo: signal → **GPIO 13**, servo power from the phone-charger
   5 V (later: buck 6.0 V from the LiPo), grounds common with the ESP32.
4. From your laptop's browser or curl:
   - `http://<ip>/status` → plain-text state (READY + current angle)
   - `http://<ip>/setup` → parks the servo at the release angle (this is the
     drum-mounting zero — you'll use it during claw assembly)
   - `http://<ip>/grip` and `/release` → the servo sweeps.

**Checkpoint:** grip/release over WiFi with nothing but a USB cable powering
the board. This is the entire wireless-claw control path proven; the LiPo +
buck + switch just make it cordless later.

## Phase 10 — Camera (already verified live)

The innomaker is **index 1** (`python -m scripts.camera_view --list` to
re-check). The consoles merged into one app (docs/APP.md):
`python -m roomcleaner.app --live --camera 1` → http://localhost:8000 for the
live camera view; `python -m roomcleaner.app --sim` → same URL to fly
simulated missions.

---

## What this bench phase deliberately leaves out

| Waiting on | Item |
|---|---|
| 3D printer access | corner mounts, spools, claw frame/hub/standoffs, controller case, camera bracket |
| TPU (unordered) | the five fingers |
| LiPo + balance charger + slide switch (unordered) | cordless effector |
| Servo horn measurement (calipers) | tendon drum print |
| Room measurement | real coordinates in `config.py`, raceway quantity |

When the printer is back: print the fit-test pair first (one spool, one
corner mount), then it's rig-assembly time — that sequence is
`cad/README.md` + `docs/FIRMWARE.md`.

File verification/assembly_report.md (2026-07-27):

# Claw assembly — integration verification report

Integrator: integration-agent (Sonnet). Assembled from `cad/parts/*.py`
(all PASS per `verification/claw_parts_report.md`, dated 2026-07-27) and
`cad/interfaces.py`. Read-only against part files; edited only
`cad/export_all.py` (registered the 3 new parts + rebuilt `build_assembly()`
to the real standoff stack-up) and this report. Date: 2026-07-27.

Reproducible via `cad.export_all.placed_components()`, which returns every
claw component individually positioned (no boolean union) in the
`effector_frame`'s own build frame: plate `z ∈ [0, 5]`, corner bosses to
`z = 8`, plate TOP at `z = 5`, frame UNDERSIDE (standoff attachment) at
`z = 0`.

## Positions used (as built in `cad/export_all.py`)

| Component | Built span (local z) | Transform | Assembled span / position |
|---|---|---|---|
| standoff ×4 | z ∈ [0, 40] | translate z = −40; XY at `(HUB_MOUNT_R·cosθ, HUB_MOUNT_R·sinθ)`, θ ∈ {36, 108, 252, 324}° | z ∈ [−40, 0], r = 27 |
| hub | z ∈ [0, 12] | translate z = −(STANDOFF_LEN + HUB_THK) = −52 | z ∈ [−52, −40], top face at −40 |
| finger ×5 | z ∈ [0, 70] | rotate 180° about X; rotate (deg+90)° about Z; translate `((pocket_r − H_BASE/2)·cosθ, (pocket_r − H_BASE/2)·sinθ, −40)`, θ = 360·i/5 | mounting face flush at z = −40; base solid fills [−52, −40]; shoulder at [−54, −52]; tip at z = −110 |
| tendon_drum | z ∈ [0, 12.4] | translate z = −18.4 (drum top at DRUM_TOP_Z = −6) | z ∈ [−18.4, −6], centered on axis |
| electronics_cover | z ∈ [0, 44.4] | translate z = +5 (EFFECTOR_THK) | rim at z = 5 (plate top), roof at z = 49.4 |

**Correction found and applied (finger radial placement):** the finger part's
local frame is centered on its own axis in X (`W_BASE`, ±8 mm) but is
**not** centered in Y — `H_BASE` runs from the ventral face at local `y=0`
to the dorsal face at `y=H_BASE` (13 mm), not `±H_BASE/2`. Placing the
finger's translation origin directly at `pocket_r` (as the pre-standoff
legacy `build_assembly` did) therefore pushes the finger's actual
cross-section center `H_BASE/2 = 6.5 mm` too far outboard, overlapping the
hub by ≈445 mm³ (confirmed by direct probe — see check 3a below). Fixed by
translating to radius `pocket_r − H_BASE/2 = 27.8 mm` instead of `pocket_r`.
This is an assembly-placement correction, not a part redesign — no part
file was touched. Recommend Fable review whether the pre-standoff legacy
`build_assembly` (now replaced) had the same latent bug.

## Check 3a — pairwise boolean interference (expect ~0 mm³, tol < 1 mm³)

Method: each component built individually via `placed_components()` (no
union), then `Workplane.intersect()` pairwise; volume of the intersection
compound measured directly (not via a probe).

| Pair | Max overlap (mm³) | Result |
|---|---|---|
| frame vs standoffs | 0.000000 | PASS |
| frame vs hub | 0.000000 | PASS |
| frame vs fingers | 0.000000 | PASS |
| frame vs drum | 0.000000 | PASS |
| standoffs vs hub | 0.000000 | PASS |
| standoffs vs fingers | 0.000000 | PASS |
| standoffs vs drum | 0.000000 | PASS |
| **hub vs fingers (critical)** | **0.000000** (all 5, worst pair reported) | **PASS** |
| hub vs drum | 0.000000 | PASS |
| fingers vs drum | 0.000000 | PASS |
| cover vs frame | 0.000000 | PASS |

Before the radial-placement fix, hub-vs-fingers measured 445.1 mm³ overlap
(finger_0 worst case) — a real interference, not a false positive; the fix
above resolved it to exactly 0.000000 mm³ across all 5 fingers, confirming
the 0.2 mm/side slot clearance (`POCKET_H/W` vs `H_BASE/W_BASE`) and the
corrected `FINGER_SHOULDER_Z0` shoulder placement are both geometrically
sound. **Check 3a: PASS.**

## Check 3b — slot engagement (expect > 90% of base_solid volume)

Method: intersect each assembled finger with a slab spanning the hub's
full z-range [−52, −40]; compare to the finger's local base-solid volume
(`intersect(local_finger, slab z∈[0, BASE_SOLID=12])` = 2210.33 mm³,
computed independent of the assembly transform).

| Finger | Engaged volume (mm³) | % of expected | Result |
|---|---|---|---|
| finger_0 | 2210.33 | 100.00% | PASS |
| finger_1 | 2210.33 | 100.00% | PASS |
| finger_2 | 2210.33 | 100.00% | PASS |
| finger_3 | 2210.33 | 100.00% | PASS |
| finger_4 | 2210.33 | 100.00% | PASS |

100% engagement is expected here (not just >90%): the through-slot depth
(`HUB_THK = 12`) exactly equals the finger's un-notched `BASE_SOLID = 12`,
so the entire base-solid section is a rigid-body copy of the same material
mapped into the slab by the assembly transform. **Check 3b: PASS.**

## Check 3c — clearances (reported numbers)

| Clearance | Expected | Measured | Result |
|---|---|---|---|
| Drum flange (R16.5) to nearest standoff inner face (R = HUB_MOUNT_R − STANDOFF_OD/2 = 22.0) | ≈5.5 mm | **5.500 mm** | PASS |
| Drum bottom (z) to hub top (z) — tendon working gap | −18.4 / −40 (given) | drum bottom **−18.400**, hub top **−40.000**, gap = 21.600 mm | matches spec exactly |
| Fingertip z, cross-checked against EFFECTOR_REACH_M (cable plane z = +8) | ≈−124 (task estimate); 8 − 130 = −122 (from EFFECTOR_REACH_M) | **−110.000** (measured, min over 5 fingers) | **flag — see note** |

**Reach discrepancy note:** measured reach (cable plane z=8 to fingertip
z=−110) is **118 mm**, vs. the `EFFECTOR_REACH_M = 0.130 m` (130 mm)
parameter in `cad/interfaces.py` (D9) — a 12 mm / ~9% shortfall. This
follows directly and unavoidably from the literal placement instructions
(mounting end flush with hub TOP at z=−40, finger length 70 mm fixed by
`FINGER_LEN`): total drop = STANDOFF_LEN(40) + FINGER_LEN(70) − cable-plane
offset(8) = 102 mm... reconciling exactly requires either the finger to
mount flush with the hub BOTTOM (which D5's through-slot/shoulder design
explicitly forbids — the shoulder bears on the underside, not the topside)
or `EFFECTOR_REACH_M` to be re-derived from the corrected 40 mm standoff
stack-up. This is a **parameter/geometry reconciliation item for the Fable
lead**, not an interference defect — no boolean overlap exists, and no part
geometry was altered. Flagging in lieu of independently deciding which
value governs, per integration-agent's no-redesign restriction.

## Check 3d — assembly STEP export/reimport (tol ≤0.1 mm bbox, ≤1% volume)

Full assembly (mechanism + cover) exported to `cad/step/claw_assembly.step`
and reimported via `cq.importers.importStep`.

| Metric | Original | Reimported | Diff | Result |
|---|---|---|---|---|
| Volume (mm³) | 186547.65 | 186547.65 | 0.0000% | PASS |
| Bbox (mm) | 98.800 × 98.800 × 159.400 | 98.800 × 98.800 × 159.400 | 0.0000 / 0.0000 / 0.0000 | PASS |

**Check 3d: PASS.**

## Check 3e — renders / exports

- `cad/previews/assembly.png` — mechanism (frame + 4 standoffs + hub + 5
  fingers + drum) rendered **without** the cover, via the existing
  `render_stl` helper. Visually confirms the corrected stack-up: plate on
  top, standoffs and hub below, fingers hanging tip-down with ventral
  V-notches visible, no visible interference. **Generated, PASS.**
- `cad/step/claw_assembly.step` — full assembly **with** the electronics
  cover included, exported for the SOLIDWORKS handoff. **Generated, PASS.**

Note: the mechanism union resolves to **2 disjoint solid bodies** in the
compound — (1) frame + standoffs + hub + 5 fingers (all touching/screwed
together, 138994.8 mm³) and (2) the tendon drum, floating free in the
standoff cavity (6913.9 mm³). This is expected, not a defect: per D4/D3 the
drum has no printed-part contact with anything else in the claw — it is
retained only by the servo horn screw (through the plate, not modeled here)
and free to rotate to wind the tendons. Two solids in one STEP compound is
the correct topology for this joint.

## Mass-rollup / prior verification cross-reference

Not re-derived here (out of integration-agent's scope); see
`verification/claw_parts_report.md` check 4 (419.20 g vs 450 g budget,
PASS) — unaffected by assembly placement.

## pytest

```
python -m pytest tests/ -q
71 passed in 12.11s
```

No test file was touched; count matches the pre-integration baseline in
`verification/claw_parts_report.md`.

## Summary

| Check | Result |
|---|---|
| 3a — pairwise interference (incl. hub-vs-fingers, cover-vs-frame) | **PASS** (all 0.000000 mm³, after radial-placement fix) |
| 3b — slot engagement | **PASS** (100% of expected, all 5 fingers) |
| 3c — clearances | drum-standoff 5.500 mm (PASS vs ≈5.5 mm); drum-hub gap 21.600 mm (matches spec); fingertip reach 118 mm vs 130 mm nominal — **flagged for Fable**, not a geometry failure |
| 3d — STEP round trip | **PASS** (0.0000% volume, 0.0000 mm bbox) |
| 3e — renders/exports | **PASS** (assembly.png without cover; claw_assembly.step with cover) |

One real defect was found and fixed during integration: the finger radial
placement (translation origin vs. cross-section centroid mismatch),
previously causing ≈445 mm³ of hub/finger interference. All other placements
matched the literal stack-up instructions with zero interference. The
`EFFECTOR_REACH_M` vs. measured-fingertip discrepancy (118 mm vs. 130 mm) is
a parameter-reconciliation item, not a geometric defect, and is escalated
to the Fable lead rather than resolved unilaterally.

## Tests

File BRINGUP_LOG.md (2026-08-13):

# Local bring-up log — software + camera milestone

Live progress record for bringing the RoomCleaner **software + live-camera**
milestone up on Jasper's Windows machine (the box with the innomaker USB
camera). Committed to the repo as work proceeds so anyone watching can follow
along. Scope is **only** the software + camera milestone — hardware bench
bring-up (`docs/FIRMWARE.md`) is a separate, later sequence and is not started
here.

- Date: 2026-08-12
- Machine: Windows 11, Python 3.11.4, CPU-only (no NVIDIA GPU)
- Branch: `claude/magical-cerf-gqr7j7`

## Status: software verified ✅ — only the live camera remains (needs the USB cam plugged in)

## Checklist

- [x] 1. Clone repo + read operating docs
- [x] 2. `python quickstart.py --vision` → tests green + install-verified line
      (see deviation #1 on the count; needed fix #2 to finish on Windows)
- [x] 3. `python -m scripts.demo_sim` → `output/run.gif` (+ scene/workspace PNGs)
- [x] 4. Detector smoke test (no camera) — `YoloWorldDetector.detect()` returned
      a list without raising. **This is the step that was blocked in the cloud;
      it works here** (see finding #3).
- [x] 5a. `detect_and_plan --image <photo>` — full detect→plan pipeline on a
      still photo, camera-free (see finding #4).
- [ ] 5b. `detect_webcam --camera N` — **live** detection. NEEDS the innomaker
      camera physically plugged in. → handed to Jasper.
- [ ] 5c. `detect_and_plan --webcam N` — live detection → cable plan. Completes
      the milestone.

## Verified environment

- torch `2.13.0+cpu` (CUDA disabled — the intended CPU wheel, 122 MB, not the
  multi-GB CUDA build), opencv `5.0.0`, ultralytics `8.4.118`.
- Tests: **29 passed, 2 skipped**. The 2 skips are `tests/test_claw_geometry.py`
  and `tests/test_winch_geometry.py`, skipped only because `cadquery` isn't
  installed — that's the CAD stack (`requirements-cad.txt`), out of this
  milestone's scope. Every software/vision test passes.

## Findings & deviations

1. **Test count vs the handoff.** The handoff expected `130 passed`; this repo
   actually collects **29 tests** (`pytest --collect-only` = 29). All 29 pass
   (+2 cadquery skips). Not a failure — just a documentation mismatch worth
   flagging. Nothing was cut on this machine.
2. **Fixed: `quickstart.py` crashed on Windows.** It printed a `✅` (U+2705) on
   success, but Windows stdout defaults to cp1252 and can't encode it →
   `UnicodeEncodeError` aborted setup *after* the tests already passed. Fixed by
   forcing UTF-8 stdout/stderr at startup (commit `959897f`). Setup now finishes
   cleanly with `✅ Install verified`.
3. **The cloud blocker is cleared on the home network.** First `detect()`
   downloaded the YOLO-World weights (`yolov8s-world.pt`, 25.9 MB, GitHub),
   auto-installed CLIP (`git+https://github.com/ultralytics/CLIP.git` → clip
   1.0), and downloaded CLIP `ViT-B/32` (338 MB) from
   `openaipublic.azureedge.net` — the URL the cloud egress proxy 403'd. It
   completed 100% and `detect()` returned a list. Note: the CLIP auto-install
   printed a "restart runtime" warning but did **not** actually require a
   restart here; the same process finished successfully.
4. **detect→plan proven camera-free.** `detect_and_plan --image bus.jpg
   --classes person clothing shirt backpack --conf 0.05` detected 5 people
   (conf 0.14–0.92), mapped each to a floor (x, y), and the same Controller that
   drives the simulator planned the pickups: 3 selected within the safe
   workspace → grabbed at floor coords → delivered to hamper → parked (2
   correctly excluded as out-of-workspace). Wrote `output/detected_image.png`
   (boxes + labels + floor coords) and `output/detected_scene.png`. These are
   **stand-in** detections to exercise the planner; real *laundry* detection
   quality is validated at the live-camera step. NB: on `zidane.jpg` at default
   conf 0.25 the model returned 0 detections — expected/fine per the handoff;
   lower `--conf` to see marginal hits.

## How to finish the milestone (live camera — Jasper)

1. Plug in the innomaker USB camera. Close anything that might hold it (Zoom/
   Teams/Camera app).
2. Activate the venv and try camera indexes:
   ```
   cd C:\Users\Jasper\Code\RoomCleaner
   venv\Scripts\activate
   python -m scripts.detect_webcam --camera 1     # try 0, 1, 2 until it's the USB cam
   ```
   A resolution line prints, then live detections when a shirt/sock is in view
   (conf ≥ ~0.4). Ctrl-C to stop.
3. Then the end-to-end live plan:
   ```
   python -m scripts.detect_and_plan --webcam 1   # same index that worked above
   ```
   Reminder: floor (x, y) uses placeholder `room_width`/`room_depth` from
   `roomcleaner/config.py` until the room is measured — detection is real, the
   coordinates are not yet calibrated.

## Log

- **2026-08-12** — Session start. Verified repo access (public, `gh` as
  `Jaspario1199`), Python 3.11.4, ~37 GB free. Cloned to
  `C:\Users\Jasper\Code\RoomCleaner`. Read `CLAUDE.md` (CAD contract — this
  milestone is out of its scope) + perception code.
- **2026-08-12** — Ran `quickstart.py --vision`: vision stack installed, tests
  ran (29 passed / 2 cadquery-skipped). Hit + fixed the Windows `✅` crash
  (commit `959897f`); re-ran quickstart → clean `✅ Install verified`.
- **2026-08-12** — `demo_sim` ran the full simulated mission (4 pickups →
  hamper → park); wrote `output/run.gif`.
- **2026-08-12** — Detector smoke test passed: YOLO-World + CLIP downloaded
  (incl. the azureedge CLIP model that was blocked in the cloud); `detect()`
  returned a list. `detect_and_plan --image` on a sample photo produced 5
  detections → 3-pickup plan; annotated outputs written. Software milestone
  verified. **Remaining: live camera (5b/5c), handed to Jasper.**
- **2026-08-12** — Live camera confirmed on the **innomaker (index 1**,
  `Innomaker-U20CAM-1080p-S1`, 1280×720): probed indices, ran the real detector
  loop live on it (clean), and grabbed snapshots. (Integrated webcam = index 0.)
- **2026-08-12** — Built the **live web app** (`docs/APP.md`): a browser
  dashboard (Flask) showing the annotated camera feed + detected-items panel +
  live sensitivity slider, with a reserved panel to grow into the full
  RoomCleaner console. `python -m scripts.live_app --camera 1` → http://localhost:8000.
  Verified end-to-end (camera capture thread, inference thread @~2 fps, MJPEG +
  `/snapshot.jpg` + `/api/state`). Test suite still green. New files only
  (`roomcleaner/webapp/`, `scripts/live_app.py`, `requirements-app.txt`,
  `docs/APP.md`); nothing in cad/firmware/contracts touched.

## Session summary & how to continue (for the next / desktop session)

**Shipped this session (all on `claude/magical-cerf-gqr7j7`):**
- Software+camera milestone verified: `quickstart.py --vision` (fixed a Windows
  UTF-8 crash), `demo_sim`, detector smoke test (CLIP azureedge download works
  on a home network — the cloud blocker is gone), `detect_and_plan`.
- Live camera confirmed on the **innomaker = index 1** (integrated webcam = 0).
- **Live web app** (`docs/APP.md`, `roomcleaner/webapp/`): browser console with
  live feed + detection overlays, detected-items panel, sensitivity slider, a
  **Robot & plan** panel (nearest-first pickup plan + per-target 4-cable winch
  lengths + max tension + reachability, using the real `Controller`/`CableRobot`),
  a **3-D room view**, and an **Animate plan** toggle (GIF of the claw flying the
  route). `--demo` mode runs the whole console with simulated laundry, no camera.
- `scripts/camera_view.py`: `--list` (find the camera index), `--snapshot`, or
  live preview.

**Run it:**
```
venv\Scripts\python.exe -m scripts.live_app --camera 1   # real camera → http://localhost:8000
venv\Scripts\python.exe -m scripts.live_app --demo       # no camera, simulated laundry
venv\Scripts\python.exe -m scripts.camera_view --list    # which index is the camera
```
(Fresh clone: `python quickstart.py --vision` first. Only one program can hold
the camera at a time.)

**What is real vs. placeholder (important):** the app is a real kinematics +
statics + planner visualized in 3-D — cable lengths, load feasibility, fan
keep-out, and pickup order are correct math. It is NOT a full physics/dynamics
sim, does NOT model the whole BOM (motors/drivers/servo are abstracted to a 40 N
force limit; the drivetrain math lives in `roomcleaner/hardware/`), and runs on
**placeholder room dimensions** (`config.py` / `cad/params.py`, marked EDIT ME)
with simulated laundry in `--demo`. Camera detections are real; their floor
coordinates are not calibrated yet.

**Open / next (highest-leverage first):**
1. Measure the room → set `ROOM_WIDTH/DEPTH/HEIGHT` + fan location in
   `config.py` so coordinates are real; then calibrate the overhead camera
   mapping (homography).
2. Live-camera milestone tail (5b/5c): plug the innomaker in, hold a shirt in
   view, confirm live detections + `detect_and_plan --webcam 1`.
3. CAD casing gaps for parts being mounted (see DESIGN_STATE.md "Local bring-up
   findings"): **no printed enclosure for the base-station controller**
   (Arduino/CNC-shield + drivers) and **no limit-switch (KW12-3) mount**.
4. App extensions (camera-free): overlay the reachable workspace on the floor;
   scaffold robot status + run/pause controls.

> 2026-08-13: the two consoles above converged — `scripts/live_app.py` + `roomcleaner/webapp/` merged into the unified `python -m roomcleaner.app` (port 8000, `--live`/`--demo`); see docs/APP.md.

## 2026-08-13 — operator dashboard verified on-machine (local agent)

Picked the work back up on Jasper's machine and smoke-tested the operator
dashboard (`roomcleaner/app/`). The "Unify the consoles" merge (`bcdbb2a`)
landed on origin **during** this run, so the numbers below are from the
immediately-pre-unify build; a post-merge re-verify entry follows this one.

- `pytest tests/test_app.py` → **11/11 pass**.
- `python -m roomcleaner.app --sim` launched clean and served the dashboard
  (page title "RoomCleaner Operator", ~17 KB).
- Full sim mission via `POST /api/command {"cmd":"start"}`: phase advanced
  `SCAN → SELECT → GRAB → DELIVER`, **items picked 1 → 2 → 3**, gripper
  closed/opened over the hamper, claw pose moved through real up→across→down
  transits, and per-cable tensions stayed feasible in-band (e.g. 4.5/6.2/5.6/
  4.6 N within the 0.5–40 N motor band). `/stream.mjpg` served live multipart
  frames; `/api/status` returned full telemetry (phase, pose, tensions, log).
- **Verdict: the operator dashboard runs end-to-end in sim on this machine.**
- Camera: innomaker still reads black at index 1 (mean brightness ≈4.5) —
  covered / unlit / not re-plugged. `--live` deferred until it's aimed at a
  lit scene; sim mode needs no camera.

### Post-merge re-verify (after `git pull` of the unified console)

Re-ran the note's "first task once the merge lands" against the merged tree
(`bcdbb2a` unify + `1999e3b`):
- Full suite: **47 passed, 3 skipped** (the 3 skips are cadquery CAD-geometry
  tests, not installed in this vision venv).
- `python -m roomcleaner.app --sim` → served **http://127.0.0.1:8000**
  (title now "RoomCleaner Console" — the two consoles are one). `GET /` 200.
- Mission via `POST /api/command {"cmd":"start"}`: `SCAN → DELIVER`,
  **picked 0 → 1**, gripper toggled, cable tensions feasible throughout.
- **Unified console confirmed working end-to-end in sim on this machine.**
  Live camera (`--live --camera 1`) is the one remaining check, gated on the
  innomaker being plugged in and aimed at a lit scene.

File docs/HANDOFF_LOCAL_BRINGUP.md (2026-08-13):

> **SUPERSEDED (8/13):** this milestone completed successfully (see
> `BRINGUP_LOG.md`). The current instructions for the local agent are in
> **`UPDATE_8-13.md`** at the repo root — start there. Kept for history.

# Handoff: finish the "software + camera" milestone on the user's machine

**Audience:** an agent running with local machine access (or a network policy
that permits `openaipublic.azureedge.net`) on Jasper's computer, with the
innomaker USB camera physically present.
**Scope:** ONLY the software + live-camera milestone. Hardware bring-up
(steppers, Vref, switches) is a separate, later sequence in
`docs/FIRMWARE.md` — do not start it under this handoff.

## Project context (one paragraph)

RoomCleaner is a ceiling-mounted 4-cable robot that finds laundry with an
overhead camera and YOLO-World open-vocabulary detection, flies a tendon-driven
claw to it, and drops it in a hamper. Repo:
`github.com/Jaspario1199/RoomCleaner`, branch `claude/magical-cerf-gqr7j7`
(the default; all work lives here). `CLAUDE.md` is the operating contract —
read it before changing anything beyond this milestone's scope.

## What is already verified (do not redo)

- 130/130 pytest in a clean cloud container AND via `quickstart.py` in a
  fresh clone (venv creation → installs → self-test all green).
- `python -m scripts.demo_sim` runs the full simulated mission (4 pickups,
  hamper drops, rest park; outputs in `./output/`).
- Vision stack installs cleanly (`requirements-vision.txt`); YOLO-World
  weights (`yolov8s-world.pt`, ~26 MB) download fine from GitHub releases.
- **Known blocker hit in the cloud (the reason for this handoff):** on first
  `detect()`, ultralytics' YOLO-World `set_classes()` builds text embeddings
  with CLIP `ViT-B/32`, downloaded from `openaipublic.azureedge.net` (and it
  auto-installs `git+https://github.com/ultralytics/CLIP.git` on first run —
  after that auto-install, the process must be restarted once). The cloud
  session's egress proxy 403'd the azureedge URL. A normal home network is
  fine.

## Your task list

1. Clone the repo; `python quickstart.py --vision` (Python 3.10+). It creates
   `./venv`, installs core + vision, runs the test suite. Expect several GB
   (torch). Checkpoint: `130 passed` and the ✅ line.
2. Run `python -m scripts.demo_sim` (venv active) — sanity, and gives the user
   `output/run.gif` to look at.
3. Smoke-test the detector WITHOUT the camera first (isolates model downloads
   from camera problems): run a `YoloWorldDetector.detect()` on any indoor
   photo (see `roomcleaner/perception/vision_detector.py` docstring; classes
   are laundry words). First call downloads CLIP; if the process complains
   about the CLIP auto-install, rerun once. Checkpoint: returns a list without
   raising (detections on a non-laundry photo may be empty or "clothing" hits
   on people — both fine).
4. Plug in the innomaker camera (bare-board UVC, driverless). Find its index:
   built-in laptop cam is usually 0, innomaker 1. `python -m
   scripts.detect_webcam --camera 1` (or 0/2). Checkpoint: resolution line
   prints, then live detections when a shirt/sock is in view with conf ≥ ~0.4.
5. Run `python -m scripts.detect_and_plan` — camera detection feeding the
   winch planner; it prints the cable-length plan for the top detection.
   That completes the milestone.
6. Report results back to the user in plain language: what ran, sample
   detection lines, and any deviations.

## Gotchas already discovered

- `detect_webcam.py` takes `--camera N` (added for exactly this bring-up).
- Floor (x, y) coordinates use placeholder room dimensions from
  `roomcleaner/config.py` (`room_width`, `room_depth`) until the user measures
  the room — detection quality is real, coordinates are not yet.
- Torch install: use the default CPU wheel; do NOT chase CUDA unless the
  machine obviously has an NVIDIA GPU. CPU inference at ~1–2 fps is fully
  adequate (the detector loop sleeps 0.2 s between frames anyway).
- Windows: activate venv with `venv\Scripts\activate`; quickstart handles
  venv paths itself.
- If OpenCV opens the wrong device or a black frame, close any app using the
  camera (Zoom/Teams hold it), then re-try index hunting.

## Boundaries

- Do not modify `cad/`, `firmware/`, contracts (`cad/interfaces.py`,
  `cad/params.py`), or the source-of-truth docs (`REQUIREMENTS.md`,
  `DECISIONS.md`) — all verified under the CAD workflow in `CLAUDE.md`.
- Small fixes needed to complete THIS milestone (e.g., a camera-index quirk,
  an import guard) are fine: commit with a clear message and push to
  `claude/magical-cerf-gqr7j7`.
- If something fails outside this scope, record it in `DESIGN_STATE.md` under
  a "local bring-up findings" heading and stop rather than improvising.

## After this milestone (context only — not yours)

Hardware bench sequence is staged in `docs/FIRMWARE.md` (first-power
checklist: Vref 0.8 V on the A4988s, single-motor test, `S` switch test).
Pending user measurements that gate two prints: servo round-disc horn
(→ `HORN_POCKET_DIA`, tendon drum) and motor shaft across-flat sanity check
(spool). Parts still unordered are tracked in `docs/SHOPPING_LIST.md`.

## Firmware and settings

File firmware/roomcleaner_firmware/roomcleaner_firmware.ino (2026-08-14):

/*
 * RoomCleaner firmware -- Arduino Uno + CNC Shield V3 + 4x stepper drivers (A4988/DRV8825) + 1 servo.
 *
 * Drives the four winch steppers and the gripper servo, homes on limit switches,
 * and takes simple newline commands over USB serial from the Python host:
 *
 *   H            -> home all winches to their switches, replies "HOMED"
 *   M a b c d    -> move winches to absolute step counts a b c d, replies "DONE"
 *   G <deg>      -> set gripper servo angle, replies "OK"
 *   ?            -> replies "POS a b c d"
 *   S            -> replies "SW x y z a" (1 = switch pressed / wire fault)
 *
 * Needs the AccelStepper library (Library Manager -> "AccelStepper").
 *
 * Pin map = standard CNC Shield V3 (GRBL layout) with the 4th axis on D12/D13.
 * Because D12/D13 are the A-axis, the 4th endstop and the servo live on the
 * analog pins (used as digital). Verify against your board silkscreen.
 */

#include <AccelStepper.h>
#include <MultiStepper.h>
#include <Servo.h>

// ---- Pins (CNC Shield V3) -------------------------------------------------
const int EN_PIN = 8;               // driver enable (active LOW)
// step, dir per axis:  X, Y, Z, A
const int STEP_PINS[4] = {2, 3, 4, 12};
const int DIR_PINS[4]  = {5, 6, 7, 13};
// limit switches (NC to GND): X=D9, Y=D10, Z=D11, A=A3(17). INPUT_PULLUP.
const int LIMIT_PINS[4] = {9, 10, 11, 17};
const int SERVO_PIN = 18;           // A4

// ---- Motion tuning --------------------------------------------------------
const float MAX_SPEED = 1200.0;     // steps/sec (cap for moves)
const float ACCEL = 600.0;          // steps/sec^2
const float HOME_SPEED = 300.0;     // steps/sec while seeking the switch
const long  HOME_BACKOFF = 200;     // steps to back off after the switch trips
// Homing reels the cable IN toward the switch. Set the sign so that direction
// matches your wiring (+1 or -1 per axis).
const int   HOME_DIR[4] = {-1, -1, -1, -1};

AccelStepper steppers[4];
MultiStepper group;
Servo gripper;

void setup() {
  Serial.begin(115200);
  pinMode(EN_PIN, OUTPUT);
  digitalWrite(EN_PIN, LOW);        // enable drivers
  for (int i = 0; i < 4; i++) {
    steppers[i] = AccelStepper(AccelStepper::DRIVER, STEP_PINS[i], DIR_PINS[i]);
    steppers[i].setMaxSpeed(MAX_SPEED);
    steppers[i].setAcceleration(ACCEL);
    group.addStepper(steppers[i]);
    pinMode(LIMIT_PINS[i], INPUT_PULLUP);
  }
  gripper.attach(SERVO_PIN);
  Serial.println("READY");
}

// Switches are wired Common + NC to GND with INPUT_PULLUP (fail-safe):
// at rest the NC contact holds the pin LOW; pressing the lever OPENS the
// circuit and the pullup takes the pin HIGH. A broken/unplugged wire also
// reads HIGH, i.e. "pressed" -- the axis refuses to move instead of
// grinding past a dead switch.
bool pressed(int i) { return digitalRead(LIMIT_PINS[i]) == HIGH; }

void homeAll() {
  // Home one axis at a time -- safer for cables (avoids tangling).
  for (int i = 0; i < 4; i++) {
    steppers[i].setSpeed(HOME_SPEED * HOME_DIR[i]);
    while (!pressed(i)) {
      steppers[i].runSpeed();
    }
    steppers[i].setCurrentPosition(0);
    // Back off the switch a touch so it isn't held.
    steppers[i].moveTo(-HOME_DIR[i] * HOME_BACKOFF);
    while (steppers[i].distanceToGo() != 0) steppers[i].run();
    steppers[i].setCurrentPosition(0);
  }
  Serial.println("HOMED");
}

void moveTo4(long a, long b, long c, long d) {
  long targets[4] = {a, b, c, d};
  group.moveTo(targets);
  group.runSpeedToPosition();       // blocks until all four arrive
  Serial.println("DONE");
}

void loop() {
  if (!Serial.available()) return;
  String line = Serial.readStringUntil('\n');
  line.trim();
  if (line.length() == 0) return;
  char cmd = line.charAt(0);

  if (cmd == 'H') {
    homeAll();
  } else if (cmd == 'M') {
    long a, b, c, d;
    if (sscanf(line.c_str(), "M %ld %ld %ld %ld", &a, &b, &c, &d) == 4) {
      moveTo4(a, b, c, d);
    } else {
      Serial.println("ERR bad M");
    }
  } else if (cmd == 'G') {
    int deg;
    if (sscanf(line.c_str(), "G %d", &deg) == 1) {
      gripper.write(constrain(deg, 0, 180));
      Serial.println("OK");
    } else {
      Serial.println("ERR bad G");
    }
  } else if (cmd == 'S') {
    // Switch states for bench testing: 1 = pressed (or wire fault), 0 = at rest.
    Serial.print("SW ");
    for (int i = 0; i < 4; i++) {
      Serial.print(pressed(i) ? 1 : 0);
      Serial.print(i < 3 ? ' ' : '\n');
    }
  } else if (cmd == '?') {
    Serial.print("POS ");
    for (int i = 0; i < 4; i++) {
      Serial.print(steppers[i].currentPosition());
      Serial.print(i < 3 ? ' ' : '\n');
    }
  } else {
    Serial.println("ERR unknown");
  }
}

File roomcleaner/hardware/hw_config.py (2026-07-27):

"""
Hardware constants for the host<->Arduino bridge. These describe the physical
drivetrain so the host can convert a cable length (meters) into motor steps.

MEASURE / MATCH these to your build:
  * MICROSTEP must match the jumpers under the DRV8825 drivers on the CNC shield.
  * DRUM_DIA_M must match your printed winch_spool drum diameter.
  * HOME_CABLE_LENGTHS is a calibration -- see driver.py.
"""

import math

# --- Stepper drivetrain ----------------------------------------------------
STEPS_PER_REV = 200          # 1.8-degree stepper => 200 full steps/rev
MICROSTEP = 16               # DRV8825 microstepping set by the shield jumpers
DRUM_DIA_M = 0.020           # m, winch spool drum diameter (cad SPOOL_DRUM_DIA)

DRUM_CIRC_M = math.pi * DRUM_DIA_M
STEPS_PER_M = STEPS_PER_REV * MICROSTEP / DRUM_CIRC_M   # ~50930 steps per meter

# --- Serial link -----------------------------------------------------------
SERIAL_PORT = "/dev/ttyUSB0"   # Windows: "COM3"; Mac: "/dev/tty.usbserial-XXXX"
BAUD = 115200

# --- Gripper servo angles (degrees) ---------------------------------------
# MUST equal cad/interfaces.py SERVO_GRIP_DEG (drum sizing depends on the 120 deg throw).
GRIP_ANGLE = 140             # tendon pulled -> tentacles curled (grip)
RELEASE_ANGLE = 20           # tendon slack -> tentacles open (release)

# --- Wireless effector (ESP32 on the claw) --------------------------------
# The gripper servo lives on an ESP32 on the effector, commanded over WiFi.
# Set EFFECTOR_HOST to the ESP32's IP (or mDNS name) once it's on your network.
EFFECTOR_HOST = "roomcleaner-claw.local"   # or e.g. "192.168.1.50"
EFFECTOR_PORT = 80

# --- Motion ----------------------------------------------------------------
MOVE_STEP_M = 0.15           # how finely to sample a path into hardware moves

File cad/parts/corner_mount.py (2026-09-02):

"""
Corner mount -- a single rigid printed bracket that anchors the winch to a
ceiling joist (or high on a wall stud) and unifies TWO jobs that used to be
two separate parts:

  1. the NEMA17 motor bracket (was motor_mount.py), and
  2. the Dyneema pulley redirect (was corner_guide.py).

Casting both onto one base plate removes a joint (and its alignment error)
between the motor and the take-off pulley, which is exactly the alignment
that matters for a clean winch fleet angle. motor_mount.py and
corner_guide.py are UNCHANGED and unused by this part; this is a standalone
replacement, not a wrapper around them.

Coordinate frame (local to this part):
    XY = the base plate. Z=0 is the plate BOTTOM (the face that contacts the
    joist/stud), +Z runs up away from the joist -- matching the "Z up from
    the mounting face" habit used elsewhere in cad/parts. The plate top
    (accessible) face is at Z=PLATE_T. The motor bracket wall and the pulley
    ears both rise from the plate TOP in +Z. +X runs from the motor bracket
    end of the plate to the pulley end. +Y runs from the motor's overhang
    side toward the far side of the plate.

Wood-screw holes: countersunk from the plate TOP face (the face away from
the joist -- that's the face you drive the screws from, and where the screw
heads must sit flush). The screw SHANK continues straight down through the
rest of the plate into the joist below Z=0.

Print orientation: plate BOTTOM (Z=0, the joist face) flat on the print bed,
no supports. This puts every countersink's wide opening at the top (away
from the bed) and its narrow point at the bottom -- each layer's hole gets
WIDER as printing proceeds upward, which is the standard self-supporting
countersink orientation (no bridging, no overhang). The wall and its two
gussets rise from the plate in +Z (they print as they go, never overhanging)
-- gusset hypotenuse angle from vertical is atan(GUSSET_RUN / GUSSET_HEIGHT)
(see value printed in __main__), comfortably under the ~45 deg
self-supporting limit given how short GUSSET_RUN is (see LEAD RULING below
for why). The wall's NEMA17 boss hole is a horizontal through-hole (same
situation as the existing motor_mount.py bracket, which prints the same way
today) -- FDM handles a round horizontal hole as a self-arching bridge
without supports.

LEAD RULING on fleet-angle geometry (supersedes an earlier, geometrically
wrong reading -- kept here for the record):

  The first draft of this part read "pulley groove mid-plane coplanar with
  the spool's drum mid-length plane" by keeping both the wall and the ears
  symmetric about the plate's Y=0 centerline, with the spool axis along X
  (pointing at the pulley). That is wrong: a spool with its axis along X
  pays line off in the plane PERPENDICULAR to X (a YZ plane) -- the line
  leaving the drum has zero X-velocity and can never reach ears sitting
  further along +X. The Y=0-centerline reading happened to be parallel to
  the line's own travel plane, i.e. exactly the wrong constraint to satisfy.

  CORRECTED LAYOUT (this part, as built):
    * The base plate, its 3 countersunk wood-screw holes, and the pulley
      ears are UNCHANGED from the first draft: ears at the plate's +X end,
      axle along Y, pulley groove mid-plane = the XZ plane at Y=0 (the
      ears' own Y midpoint, by symmetric construction).
    * The motor bracket wall is rotated 90 deg about Z: it is now thin in Y
      (WALL_THK), wide in X (WALL_W), sitting near the plate's -X end, at
      NEGATIVE Y (clear of the Y=0 screw centerline). The NEMA17 bolt
      pattern is cut into the wall's -Y face; the motor BODY bolts there
      and hangs further in -Y (it overhangs the plate edge -- see
      MOTOR_BODY_OVERHANG_Y in __main__ -- which is accepted: the motor is
      cantilevered on a stiff bracket, not resting on the plate). The
      motor's output SHAFT passes back through the wall (+Y) via the boss
      clearance hole and continues +Y into the open plate area, where the
      (separately-modeled) spool would sit.
    * With the spool's axis now along Y, it pays line off in an XZ plane --
      the SAME kind of plane the pulley groove mid-plane is. The wall's
      front (+Y) face is positioned so the spool's drum MID-LENGTH lands
      exactly on Y=0 (WALL_FRONT_Y = -(FACE_TO_SPOOL + SPOOL_FLANGE_THK +
      SPOOL_LEN / 2)): the drum's own mid-length cross-section is then the
      XZ plane at Y=0 -- genuinely coplanar with the pulley groove
      mid-plane, independent of FACE_TO_SPOOL, with 0 mm nominal error.
    * Fleet SEPARATION is now measured along X (shaft/boss X position vs.
      EAR_CX), not Y -- both keep their original meaning under the
      corrected orientation.
    * CORNER_MOUNT_AXIS_Z (shared shaft/boss and pulley-axle height) is
      unchanged -- rotating the wall about Z does not touch Z.

  This resolves the self-contradiction the first draft flagged: the
  coplanarity condition, the >=60 mm separation, and the plate envelope are
  now all simultaneously satisfiable, because separation and coplanarity
  are measured along DIFFERENT axes (X and Y respectively) instead of
  competing for the same one.

  Side effect on the gussets: with the wall pinned by the coplanarity
  requirement, the plate's own back edge leaves only a few mm behind the
  wall's back face -- nowhere near enough for a full-size gusset run on
  its own. The pulley/spool (+Y) side of the wall is even more constrained:
  the spool flange's underside sits only CORNER_MOUNT_SPOOL_PLATE_CLEARANCE
  above the plate, well short of a useful gusset height. Per lead direction,
  the gussets go on the -Y (motor-body) side; BASE_W and FACE_TO_SPOOL are
  tuned (see GUSSET_RUN below) so a full GUSSET_RUN=10 mm still fits within
  the plate footprint back there.
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

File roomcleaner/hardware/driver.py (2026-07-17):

"""
Host-side motor driver: converts effector positions into winch step targets and
speaks the serial protocol to the Arduino firmware.

Protocol (newline-terminated ASCII, easy to debug in a serial monitor):
    host -> mcu     mcu -> host
    H               HOMED        home all winches to their limit switches
    M a b c d       DONE         move winches to absolute step counts a,b,c,d
    G <deg>         OK           set the gripper servo angle
    ?               POS a b c d  query current step counts

Step convention: a winch's step target is how far its cable has been paid out
FROM its homed length, in steps:

    steps_i = round( (cable_length_i(P) - HOME_CABLE_LENGTHS[i]) * STEPS_PER_M )

The base `Driver` holds all the logic and is fully testable; `SerialDriver` adds
the real pyserial transport, and `MockDriver` records commands for tests / dry
runs.
"""

from __future__ import annotations

import numpy as np

from .hw_config import STEPS_PER_M, GRIP_ANGLE, RELEASE_ANGLE, SERIAL_PORT, BAUD


class Driver:
    """Transport-agnostic driver: builds commands, converts lengths to steps."""

    def __init__(self, robot, home_lengths=None, steps_per_m: float = STEPS_PER_M):
        self.robot = robot
        self.steps_per_m = steps_per_m
        # Home cable lengths: the length of each cable when its winch is homed
        # against its limit switch. CALIBRATE after building (measure each cable).
        # Default: the lengths at the robot's rest pose -- a reasonable placeholder.
        if home_lengths is None:
            home_lengths = robot.cable_lengths(robot.find_rest_position())
        self.home_lengths = np.asarray(home_lengths, dtype=float)
        self.homed = False

    # -- length <-> steps ---------------------------------------------------
    def steps_for_point(self, point) -> list[int]:
        """Absolute winch step targets to place the effector at `point`."""
        lengths = self.robot.cable_lengths(point)
        return [int(round((L - Lh) * self.steps_per_m))
                for L, Lh in zip(lengths, self.home_lengths)]

    # -- high-level commands ------------------------------------------------
    def home(self):
        self._command("H", expect="HOMED")
        self.homed = True

    def move_to_point(self, point):
        if not self.homed:
            raise RuntimeError("Home the winches before moving (call home()).")
        s = self.steps_for_point(point)
        self._command(f"M {s[0]} {s[1]} {s[2]} {s[3]}", expect="DONE")

    def grip(self):
        self._command(f"G {int(GRIP_ANGLE)}", expect="OK")

    def release(self):
        self._command(f"G {int(RELEASE_ANGLE)}", expect="OK")

    # -- transport (overridden by subclasses) -------------------------------
    def _command(self, line: str, expect: str | None = None):
        raise NotImplementedError


class MockDriver(Driver):
    """Records commands instead of sending them -- for tests and dry runs."""

    def __init__(self, robot, home_lengths=None, **kw):
        super().__init__(robot, home_lengths, **kw)
        self.commands: list[str] = []

    def _command(self, line: str, expect: str | None = None):
        self.commands.append(line)


class SerialDriver(Driver):
    """Talks to the Arduino firmware over USB serial (needs `pyserial`)."""

    def __init__(self, robot, home_lengths=None, port: str = SERIAL_PORT,
                 baud: int = BAUD, timeout: float = 30.0, **kw):
        super().__init__(robot, home_lengths, **kw)
        self.port, self.baud, self.timeout = port, baud, timeout
        self._ser = None

    def open(self):
        try:
            import serial
        except ImportError as exc:  # pragma: no cover
            raise ImportError("SerialDriver needs pyserial: pip install pyserial") from exc
        self._ser = serial.Serial(self.port, self.baud, timeout=self.timeout)
        # Arduino resets on connect; wait for its READY banner.
        self._readline()
        return self

    def _readline(self) -> str:
        return self._ser.readline().decode(errors="replace").strip()

    def _command(self, line: str, expect: str | None = None):
        if self._ser is None:
            raise RuntimeError("Call open() before sending commands.")
        self._ser.write((line + "\n").encode())
        if expect is None:
            return
        while True:
            resp = self._readline()
            if resp.startswith(expect):
                return
            if resp.startswith("ERR"):
                raise RuntimeError(f"Firmware error for '{line}': {resp}")
            if resp == "":
                raise TimeoutError(f"No '{expect}' reply to '{line}'.")

    def close(self):
        if self._ser is not None:
            self._ser.close()
            self._ser = None

    def __enter__(self):
        return self.open()

    def __exit__(self, *exc):
        self.close()

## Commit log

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2026-07-16 Add complete cart-ready Amazon BOM checklist
    Consolidate the hardware research into a single orderable checklist
    (docs/BOM_ORDER.md): grouped by subsystem, checkboxes, links or search
    terms for every line, and totals. Close the two gaps that made the earlier
    BOM not fully orderable -- winch spools and the gripper were 3D-printed, so
    add Amazon "no-printer swap" alternatives -- plus specific search terms for
    the misc power/wiring items that previously lacked links.
    Claude-Session: https://claude.ai/code/session_012vxDhJBdXDDzxaEvKJXH5D
2026-07-16 Add parametric CAD (STEP+STL) and a tentacle gripper; BOM base/upgrade tiers
    Print everything printable. All mechanical parts are parametric CadQuery
    scripts exporting genuine STEP + STL (plus preview PNGs), driven by
    cad/params.py so they adapt to your motor shaft / line / servo.
    Parts: winch_spool x4, motor_mount x4, corner_guide x4, effector_frame,
    tentacle_hub, tentacle_finger x5, camera_mount. `python -m cad.export_all`
    regenerates all files and an assembled-gripper preview.
    Gripper redesign -> tentacle hand: a ring of tendon-driven curling TPU
    fingers (continuous dorsal skin, ventral V-notches, tendon channel) that
    one servo curls inward to rake and wrap crumpled laundry. Better than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
    [_assembly.stl, camera_mount.step, camera_mount.stl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]
2026-07-16 Lock in final "shirts & jeans" build; add Phase 5 (cable 3D printer)
    Re-scope to the real payload (shirts/pants/jeans, ~2 lb max) and the parts
    that actually need it:
    - config.py: model the LOADED effector (0.45 kg assembly + 0.9 kg jeans =
    1.35 kg) so the workspace/tension math validates under load. Peak cable
    tension across the workspace is 15 N.
    - CAD: switch to NEMA 17 steppers -- winch_spool bore 6->5 mm and a new
    NEMA 17 L-bracket motor_mount (face-mount pattern + gussets). Regenerated
    all STEP/STL.
    - BOM_ORDER.md rewritten as the final ~$184 build: NEMA 17 steppers + one
    CNC shield (replaces the ESP32 + 4 big drivers), 12V 5A supply, home
    switches kept in, printed corner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
    [camera_mount.step, corner_guide.step, effector_frame.step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]
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2026-07-16 Shopping list: switch motor to SIMAX3D 42-38 5-pack (spare + cheaper)
    Swap the $54 59Ncm 4-pack for the SIMAX3D NEMA 17 42-38 5-pack (~36 N·cm,
    1.5 A) at $33: 36 N·cm is ~2.4x the torque this build needs, the 1.5 A rating
    lets the A4988 drivers run it at full torque (no throttling), and the 5-pack
    includes a spare motor while costing ~$21 less. Totals updated
    (~$235 full / ~$194 trimmed). Driver note updated accordingly.
    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
2026-07-17 Shopping list: DAOKI DRV8825 CNC kit for the controller
    Swap the A4988 kit ($24) for the DAOKI CNC Shield V3.0 kit ($17): bundles
    Uno + shield + 4x DRV8825 + heatsinks + USB + DC power cable + jumpers.
    DRV8825 run cooler and drive the 1.5 A motors at full torque; the included
    DC power cable likely makes the separate $8 barrel adapter redundant. Added a
    4th-axis firmware caveat (stock GRBL clones the A axis; our custom firmware
    drives all four independently). Totals down to ~$180-220. Also switch the
    line note to 50 lb braid earlier.
    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
2026-07-17 Add printable overhead-camera bracket for the innomaker board
    cad/camera_mount_overhead: a ceiling plate that holds the innomaker 32x32
    board camera lens-down on standoffs (USB-connector clearance behind, cable
    slot through the plate, 4 corner ceiling screws). Saves the $14 metal case.
    Added to export_all, cad/README parts table, and referenced from the
    shopping list. Hole pattern (28 mm square) is parametric -- verify against
    the board before printing. All 8 parts regenerated.
    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
    [camera_mount.step, camera_mount_overhead.step, camera_mount_overhead.stl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]
2026-07-17 Shopping list: fix servo to STANDARD 180 MG996R (not 360 continuous rotation)
    The gripper needs a positional servo that holds a curl angle; a
    continuous-rotation (360) servo only controls speed/direction and can't hold
    position. Correct the pick + link and flag the distinction explicitly.
    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
2026-07-17 CAD: make hub-to-frame joint heat-set-insert ready (toggle in params)
    Add USE_HEATSET_INSERTS to params.py; when on, the 4 tentacle_hub->frame
    mounting holes widen to ~4mm for M3 brass inserts (the joint that carries the
    whole gripper). Clearance holes, screw-into-metal holes, and TPU parts are
    unaffected (inserts don't hold in TPU). Documented in cad/README; STLs
    regenerated. Toggle off to revert to self-tap holes.
    [_assembly.stl, camera_mount.step, camera_mount_overhead.step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]
2026-07-17 Shopping list: ceiling anchors = 5in M10 closed-eye lag hooks 700lb (correct thread type)
    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
2026-07-17 Wireless effector: gripper on an ESP32 over WiFi (no wire to the claw)
    Split the gripper off the wired Arduino so only the 4 Dyneema cables touch the
    effector. Grip/release aren't time-critical, so WiFi is safe here (unlike the
    synchronized winch motion, which stays wired).
    - firmware/effector_esp32.ino: ESP32 on the claw joins WiFi and serves
    GET /grip / /release to drive the servo off an onboard LiPo.
    - hardware/gripper.py: swappable gripper backends -- WiFiGripper (HTTP to the
    effector, stdlib only), SerialGripper (wired fallback), MockGripper (tests).
    - executor.run_on_hardware gains a `gripper` arg: motors go to the serial
    driver, grip/release to the wireless gripper. Backward co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
    [_assembly.stl, camera_mount.step, camera_mount_overhead.step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]
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2026-07-22 Add 3 practical analysis sims: payload, calibration, workspace volume
    - sim_payload_sweep.py: exploits tension's linearity in load to find the max
    liftable weight -- ~4 kg anywhere / ~10.6 kg at center vs the 40 N limit
    (jeans are 0.9 kg, so huge margin).
    - sim_calibration_sensitivity.py: perturbs the anchor positions and measures the
    resulting claw error via forward kinematics -> "measure your ceiling corners to
    ~2 cm for ~2 cm grab accuracy."
    - sim_workspace_volume.py: sweeps is_reachable over a 3D grid and renders the
    reachable point cloud (~63% of the room box).
    README quickstart updated. 29 tests pass.
    Claude-Session: ht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
2026-07-22 Showcase: expandable BOM, live force explorer, arch diagram, portfolio handoff
    - BOM section: five expandable subsystem groups (component / purpose / qty),
    engineering-first descriptions; per-item pricing hidden behind a
    "show est. pricing" toggle so recruiters see the $230 total by default.
    - Force explorer: drag the claw on a floor map, adjust payload (0-5 kg) and
    height sliders; the four cable tensions are solved LIVE in JS using the same
    min-norm + null-space-centered statics as the Python (cable thickness/color
    encodes load, bars show N vs the 40 N limit, plus a max-payload-here readout
    and an infeasible state).
    - Architecture diagram (mono, instrument style), status line, G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
2026-07-27 CAD workflow bootstrap: contracts, gates 1-3, calc review corrections
    Install the CAD engineering handoff as CLAUDE.md (project block filled) and
    the four Sonnet agent definitions. Record Gate 1-3 artifacts: REQUIREMENTS.md
    (R1-R18 + acceptance), DECISIONS.md (D1-D10), calculations/claw_integration.md
    (C1-C6), DESIGN_STATE.md (adaptation map + in-flight plan).
    New authoritative contract files: cad/interfaces.py (every mating value once --
    which exposed a latent frame/hub bolt-circle mismatch, 27.0 vs 23.6 mm, now
    unified at HUB_MOUNT_R=27 @ [36,108,252,324] deg) and cad/materials.py.
    cad/params.py re-exports the contracts and gains authoritative NOTCH_GAP.
    Independent calc review (verifica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
2026-07-27 Gate 5 verified all parts; lead caught + fixed shoulder placement spec error
    geometry-verifier: all six claw parts PASS (exact bboxes, frame<->hub bolt
    circle identity, through-slots, shoulder/slot fit, drum winding 28.27 mm >= 27,
    cover<->frame tab alignment, STEP round-trips 0.0000 diff). Mass rollup 419.2 g
    vs 450 g budget. tests/test_claw_geometry.py adds 42 permanent checks; stale
    G-120 grip assertion corrected to the contracted 140.
    Lead review before integration caught a spec error of the lead's own making:
    the finger shoulder was placed at the mounting end (z 0-2), where its oversize
    would have prevented the base from entering the hub slot at all (zero
    engagement/anti-rotation). Cor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
    [tentacle_finger.step, tentacle_finger.stl, tentacle_hub.step]
2026-07-27 Gate 6 complete: claw assembly integrated, verified, contracts trued
    integration-agent rebuilt build_assembly() to the real stack-up (standoffs on
    the shared bolt circle, hub at -52, shouldered fingers through-slotted flush,
    drum under the plate, cover on top): pairwise interference 0.000 mm^3 across
    all pairs, slot engagement 100% on all five fingers, drum<->standoff clearance
    5.50 mm, assembly STEP round-trip exact. It also caught and corrected a real
    placement bug: the finger's ventral-anchored local frame put fingers 6.5 mm
    outboard (445 mm^3 hub interference) -> translate at pocket_r - H_BASE/2 (D11).
    Its reach measurement exposed a lead calc error: C5 double-counted the hub
    (the finge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
    [_assembly.stl, camera_mount.step, camera_mount_overhead.step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]
2026-07-27 Tier 2a: true fastener-length contracts, rewrite stale assembly procedure
    Writing the real assembly procedure against the D2-D8 stack-up surfaced two
    fastener-length contract errors: the hub-side standoff screw must be M3x16
    (an M3x8 cannot span the 12 mm hub to reach the standoff's bottom insert) and
    the finger retainer must be M3x12 (a 16 bottoms out in the 11 mm tap through
    the open slot). interfaces.py corrected.
    cad/README.md: assembly section rewritten from the obsolete hub-under-frame
    description to the verified standoff architecture -- insert prep, /setup servo
    zeroing before horn attach, inverted servo, finger insertion orientation,
    through-bore tendon tensioning, buck-before-servo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
2026-07-27 README: insert locations updated to standoff architecture (standoff ends + cover tabs; hub holes are clearance)
    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
    [camera_mount.step, corner_guide.step, motor_mount.step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]
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2026-07-28 Winch-side verification: 2 real defects found (spool D-flat no-op, guide ear walls)
    geometry-verifier swept the five pre-discipline winch/camera parts:
    motor_mount, camera_mount, camera_mount_overhead PASS (all probes exact).
    winch_spool FAIL: bore correctly 5.2 mm (followed the NEMA 17 change) but the
    D-flat cut ends exactly at the bore surface -- a geometric no-op; the bore is
    round and MOTOR_SHAFT_FLAT has zero effect. corner_guide FAIL: 3.7 mm axle
    holes through 4.0 mm ears leave ~0.15 mm walls, unprintable. Permanent tests
    in tests/test_winch_geometry.py document both (2 failing by design until
    repaired); full probe evidence in verification/winch_parts_report.md.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
    [test_winch_geometry.py]
2026-07-28 Tier 2 closed: winch defects repaired, defective verifier test rewritten
    cad-implementer (repair 1/2, both approved on lead review):
    - winch_spool: true D-flat -- a flat cannot be made by cutting MORE out of a
    round hole; bore cutter is now intersected with the x <= bore_r-FLAT
    half-space so the chord sliver stays solid. Measured wall at y=0: 2.100 mm
    (exact); round side 2.600 mm; bbox unchanged.
    - corner_guide: EAR_PLATE_T=7.0 sizes the plate through the axle hole
    (walls 1.65 mm >= 1.5 min) while EAR_T keeps driving positions, so hole
    location/diameter tests stay valid. bbox unchanged.
    The implementer correctly escalated the remaining red test: the verifier's
    ear-wall check hardc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
    [corner_guide.step, corner_guide.stl, winch_spool.step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]
2026-08-06 Swap sold-out DAOKI controller kit for ELEGOO starter kit + ACEIRMC shield
    The DAOKI Uno+CNC-shield+DRV8825 kit went out of stock at order time.
    Replace it with the ELEGOO UNO R3 Super Starter Kit (~$45, Uno plus a
    200-piece component library for future projects) plus the ACEIRMC CNC
    Shield V3 with 4x A4988 (~$10). Document the A4988 derated current
    limit and Vref procedure (0.8 V/A on R100 sense resistors) alongside
    the DRV8825 formula, list the HiLetgo DRV8825 5-pack as the optional
    full-current upgrade, and note the Sevenmore DRV8825 kit as the
    like-for-like budget alternative. The lost kit DC power cable is
    covered by landing the PSU leads directly in the shield screw terminal.
    Co-Autho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
2026-08-07 Replace hanging eye-hook anchors with rigid corner mounts (D13)
    A hook is a pivot: the corner winch/pulley assembly could swing, moving
    the anchor point the kinematics and calibration treat as fixed. Record
    D13 adopting a printed corner_mount plate (NEMA 17 bracket + pulley ears
    on one base, 3x #10 x 3in wood screws into a joist or wall stud) and
    swap the shopping list line: eye hooks out, wood screws in.
    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
2026-08-07 Fix corner_mount fleet layout: rotate motor bracket 90 degrees
    Repair of the defect flagged in the WIP commit: the spool axis pointed
    along the plate toward the pulley, so the line would pay off
    perpendicular to the groove plane. The wall is now thin in Y at
    negative Y near the -X end, shaft along +Y, so the spool axis and
    pulley axle are parallel and the drum mid-length plane is coplanar with
    the pulley groove mid-plane (0 mm nominal error, +-2 mm tolerance,
    verified on the built solid). Shaft-to-axle separation 100 mm along X,
    max fleet angle 7.4 deg, motor body cantilevers 38 mm past the -Y plate
    edge (accepted, D13). Tests updated to probe the rotated wall and the
    real fleet condition; 1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
    [corner_mount.step, corner_mount.stl]
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2026-08-07 Fix corner_mount gusset/motor-body interference; harden tests
    Widen the motor wall to 56 mm and drive the gusset positions off the
    real 42.3 mm NEMA 17 body half-width (+2 mm clearance) instead of the
    31 mm bolt-pattern half-width, so the motor seats flush: motor-body
    envelope interference 70.42 -> 0.000 mm3. To keep full gusset section
    within the mass budget: BASE_W 58 -> 65, BASE_L 148 -> 138,
    FACE_TO_SPOOL 3 -> 0; fleet separation 95 mm, max fleet angle 7.8 deg,
    mass 88.76 g (budget 90).
    Test hardening per the verification audit: boolean interference
    regression tests for the motor body and a virtual spool; countersink
    spacing, fleet separation, and axle coaxiality now measured on the
    bui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
    [corner_mount.step, corner_mount.stl]
2026-08-07 Close corner_mount verification cycle: docs + re-verification report
    Re-verification passed all items with independent reproduction (both
    interference volumes 0.000 mm3; the old 70.42 mm3 defect reproduced
    against the pre-repair geometry to prove the regression test is real).
    Record the cycle in DESIGN_STATE.md, mark motor_mount/corner_guide as
    superseded by corner_mount in cad/README.md, and document the spool
    rub-gap assembly ceiling (<= 2 mm, worst-case fleet ~9 deg) that the
    FACE_TO_SPOOL=0 model implies.
    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
2026-08-12 Fix inverted limit-switch polarity for NC fail-safe wiring; add S command
    pressed() treated LOW as pressed, which is Normally-Open logic; the
    documented Common+NC fail-safe wiring reads LOW at rest and HIGH when
    pressed or on a broken wire, so homing would have zeroed instantly
    without moving. Invert the check, document the fail-safe behavior, and
    add an S serial command that reports all four switch states for bench
    testing (FIRMWARE.md first-power step updated to use it).
    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
    [roomcleaner_firmware.ino]
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2026-08-12 fix(quickstart): force UTF-8 stdout so Windows setup doesn't crash on the ✅
    On Windows the console/redirected stdout defaults to cp1252, which cannot
    encode the U+2705 checkmark printed on success — quickstart.py aborted with
    UnicodeEncodeError right after the tests passed. Reconfigure stdout/stderr to
    UTF-8 at startup so setup completes cleanly (also fixes em-dash mojibake).
2026-08-12 docs(bringup): software milestone verified — install, sim, detector, detect→plan
    Records: quickstart --vision green (29 pass/2 cadquery-skip), demo_sim gif,
    detector smoke test (azureedge CLIP download works on the home network — the
    cloud blocker is cleared), and a camera-free detect→plan run. Only the live
    camera step (5b/5c) remains; instructions included.
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2026-08-12 fix(app): self-healing camera capture; drop exposure pinning that blacked the feed
    - Auto-recover a stalled/stuck UVC stream: the capture loop reopens the camera
    when reads fail (>2s) or frames go byte-identical/frozen (>3s, catches the
    stuck-black state we hit live). Adds a 'reopens' stat.
    - Revert the CAP_PROP_FPS / CAP_PROP_AUTO_EXPOSURE pinning — on this camera's
    DirectShow driver it underexposed the feed to pure black in a lit scene.
    Leaving the driver's own auto-exposure alone keeps the image visible; the
    reopen handles the stuck case, which is the real robustness win.
2026-08-12 feat(app): Robot & plan panel — pickup plan, winch cable lengths, 3D view
    Turns detections into a plan using the SAME Controller + CableRobot as the
    robot: nearest-first pickup order, per-target 4-cable (A/B/C/D) lengths + max
    tension + reachability, and a live 3D room render (winches/cables/claw/laundry/
    hamper/fan). New endpoints /api/plan and /api/room.png; full-width console panel
    in the dashboard.
    Adds --demo mode (seeds simulated laundry, no camera) so the whole console
    works offline — used to build/verify this without the disconnected camera.
    Tests still 29 passed / 2 skipped.
2026-08-12 feat(app): animate the planned path in the 3D view
    Add a Live view / Animate plan toggle to the Robot & plan panel. 'Animate plan'
    renders a GIF of the claw flying the whole route (rest -> each item -> hamper ->
    park) via the simulator's animate_run, served at /api/room.gif and cached by
    detection signature (~10s first render, instant after). Tests 29 passed/2 skipped.
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2026-08-13 corner_mount rev B: KW12-3 homing-switch mount, independently verified
    Adds a two-leg boss beside the line corridor where a stopper bead on
    the Dyneema trips the switch's roller lever during reel-in homing.
    M2 self-tap pilot slots at the switch's 9.5 mm pitch plus zip-tie
    through-slots, all X-elongated for +/-5 mm trigger-point adjustment.
    Boss never enters the Y=0+/-3 line corridor (0.000 mm3, reproduced by
    two independent constructions); switch-body envelope clear of part,
    spool, and driver-access columns; baseline geometry regression-checked
    unchanged (motor/spool interference, fleet alignment, countersinks,
    STEP round-trip). Mass 92.15 g (+3.38, local budget raised 90->93.5,
    lead-approve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
    [corner_mount.step, corner_mount.stl]
2026-08-13 base_station_case: verified controller enclosure (tray + lid)
    Printed case for the Uno + CNC Shield V3 stack: Uno bosses on the
    KiCad-verified hole pattern, 48 mm stack clearance, vented walls + lid,
    USB/DC input wall and 4-motor + endstop output wall with Z-flanked
    zip-tie strain relief, countersunk floor mounts, M3 insert lid posts
    clear of the board. 135.15 g PETG combined.
    Full workflow history in verification/base_station_case_report.md: two
    independent verification passes and two bounded repairs caught five
    real defects before printing (mid-air countersinks from a workplane
    centroid trap, USB port rotated 90 deg, lid posts inside the Uno
    footprint, a 1.27 mm hole-pattern data error, a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
    [base_station_case_lid.step, base_station_case_lid.stl, base_station_case_tray.step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]
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2026-08-14 Fix bench-guide errors found by instruction audit
    An independent audit of the beginner bench instructions against the
    firmware source and real hardware references found two blockers and
    several majors, now corrected here and in the interactive checklist:
    the CNC Shield V3's A-axis needs 2 selection jumpers on the D12/D13
    position (14 total, not 12) or the 4th motor never moves; limit
    switches wire to the two pins of ONE end-stop connector, not across
    X+ and X-; A4988 Vref target halves to 0.40 V on R050-sense boards;
    the MP1584 trimpot is a sensitive single-turn (not multi-turn) and its
    input polarity is fatal if reversed; the effector /status endpoint
    returns plain text, not JSON; firmware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
    [roomcleaner_firmware.ino]
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2026-08-28 Verify camera_case_overhead: independent geometry report (PASS)
    24 independent BRep probes + the part's own 29 tests, 52/52 green.
    Measured: 28.00 mm standoff pitch, 018.00 lens opening, 0.000 mm
    bezel-hole/boss misalignment, 45.00 g combined, STEP round-trip <0.001%
    volume error. Noted: skirt wall is exactly at the 2.4 mm spec floor;
    side cable notch suits a flexible cable but not a rigid boot.
    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
2026-09-02 corner_mount rev C: homing switch on a drop arm below the pulley (D14)
    Removes the mid-span KW12-3 boss; adds a two-leg drop arm beside the
    vertical line (X = EAR_CX + CORNER_PULLEY_OD_NOM/2) with Z-elongated
    zip-tie and M2 pilot slots (+-5 mm trigger adjust). Bead now lives on the
    vertical span and never crosses the pulley groove. New interface value
    CORNER_PULLEY_OD_NOM = 20 mm. Mass 96.72 g (+4.57 g vs rev B, budget
    105 g). Pulley envelope, line corridor and countersink clearances all
    0 mm^3. 72 winch-geometry tests pass. Independent verification report
    to follow in a separate commit.
    Claude-Session: https://claude.ai/code/session_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
    [corner_mount.step, corner_mount.stl]
2026-09-02 Verify corner_mount rev C: FAIL — switch roller misses the drop line
    Independent report: all rev-B regressions and D14 clearances pass
    (0 mm^3 interference, STEP round-trip exact, arm prints unsupported),
    but the KW12-3 mounted on the arm's vertical +X face puts its roller
    ~5 mm outboard of the line in X and 10.5 mm past it in Y: a bead on
    the drop line cannot trip it. Root cause is switch orientation (lever
    along the line instead of across it). The two key-check probes are
    marked strict-xfail pending rev D.
    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
2026-09-02 corner_mount rev D: KW12-3 on a horizontal pad, roller lands on the drop line
    Repairs the rev C defect (verification/corner_mount_revC_report.md check
    5). Switch now sits on a +Z-facing pad atop the drop arm, long axis
    along Y, roller end at Y=2.5 so the roller center rests at
    (DROP_X, 1.0, 56.5); a bead descending the line presses it toward the
    body -- the switch's real actuation direction. Corrected lever model
    (hinged far end, roller 1.5 mm past the body end, 12 mm rest height --
    caliper-verify items) replaces the 18 mm free-lever assumption. Trigger
    height set by bead placement; pilots X-elongated +-2 mm for 18-22 mm
    pulleys; zip-tie groove around the arm neck. 45 deg chamfer transition,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
    [corner_mount.step, corner_mount.stl]
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2026-09-02 corner_mount rev D.1: groove clear of pilots, r=3 corridor notch, docstring fix; verified
    Zip-tie groove rederived from the M2 pilots' blind bottom with 1.0 mm
    clearance (Z 34.5-38.5, was 37-41): full wall around every pilot at both
    tuning extremes. Pad front-lower edge notched to KW_LINE_CORRIDOR_R = 3.0
    so no printed material lies within r=3 of the drop line (was 1.125 mm^3);
    switch body overhangs the notch by <= 0.5 mm (asserted). Actuation
    direction typo corrected. Both rev D verification xfails now pass for
    real; pad-face probe moved 1.0 mm in from the notched edge. 100/100
    corner-mount tests. DESIGN_STATE records the rev C->D history.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
    [corner_mount.step, corner_mount.stl]
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
